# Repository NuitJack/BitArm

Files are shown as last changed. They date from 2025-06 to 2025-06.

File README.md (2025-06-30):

# BitArm
This project uses a RP Pico W shielded by the [BitDogLab](https://bitdoglab.webcontent.website/) team's PCB to recieve user inputs through a 2.4-inch SPI TFT display with 240x320 resolution, ILI9341 controller, and resistive touchscreen (XPT2046) to control the movements of a 3D printed Robotic Arm via BLE comunication with an ESP32-DevKitC-32, controlling three MG90S metal gear servos for the arm's degrees of freedom and one SG90 servo motor for the claw. This was developed during the first semester of 2025 as a collaborative project for Unicamp's practical course on embedded systems projects at [FEEC](https://www.fee.unicamp.br/). In this repository you will find everything we used to bring this project into reality. We thank both the support and instruction of the course's professor, [Dr. Fabiano Fruett](http://lattes.cnpq.br/4840178785453194), whose vision made this and many other great projects' development possible with that practical course's offering.

<p align="center">
  GIF with quick visual demo of the project
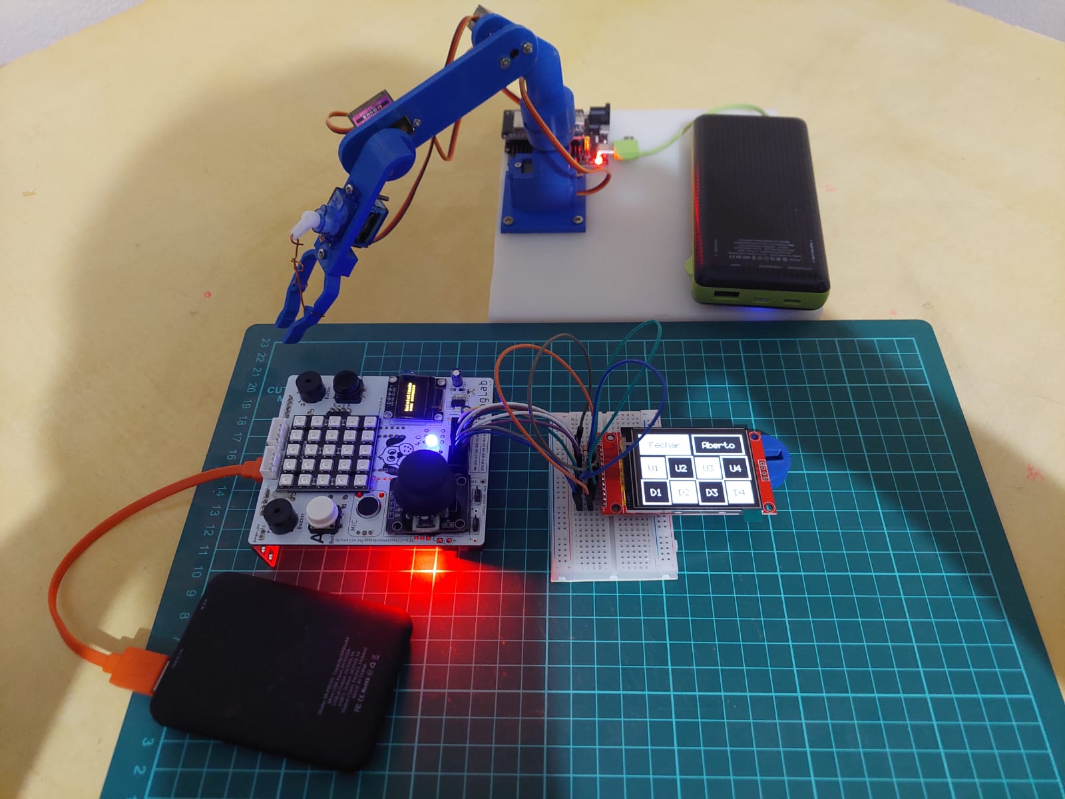
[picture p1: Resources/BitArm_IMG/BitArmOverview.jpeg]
Picture of the project
  
</p>

> Follow [this Google Drive link](https://drive.google.com/file/d/1D46ARnqftNCbvr9nV22uoLGM8FUA34ID/view?usp=sharing) to see this demo in better resolution and detail

## Directory tree
```bash
BitArm/
├── Arm/	# Contains everything that was uploaded to our ESP32 in order to control the robotic arm via BLE sent commands coded unto individual chars
├── Firmware/	# Contains the firmware file and instructions on how to build a Firmware file for RP Pico W, already with custom drivers for the display's touch and LCD interfaces
├── Resources/	# All ilustrations used for this documentation
├── main.py	# The main python routine implemented into RP Pico W, responsible for running the main user interface
└── README.md	# This file
```

## Full material list
Main set of components:
- 1x BitDogLab kit, containing a Raspberry Pi Pico W microcontroler
- 1x 2.4-inch SPI TFT display with 240x320 resolution, ILI9341 controller, and resistive touchscreen (XPT2046) with plastic pen
- 1x ESP32-DevKitC-32 with CH340C USB-Serial converter
- 1x 38-pin ESP32S NodeMCU expander. With support for USB-C and Micro USB
- 1x 20000mAh/22.5W power bank with 5V output
- 1x USB to USB-C cable
- 3x MG90S motors (base and both joints)
- 3x MG90S Horn
- 1x SG90 motor (claw)
- 1x SG90 Horn

Arm Structure:
- Structure made of PLA filament with 3D printing
- 1x 608Zz bearing

Screws and Nuts:
- MG90S Motor Mounting
  - 6x M2 X 20mm Flat Head Screws 
  - 6x Nuts for M2 Screws
- 8 sets of (1 for Claw, 6 for Joint Supports, 1 for Axis):
  - 8x M2.5 X 20mm Pan Head Screws
  - 8x Nuts for M2.4 Screws
- Base
  - 4x M4 x 10mm Screws with Superb Thread

Display wiring acessories:
- 1x Breadboard 8.5×5.5cm (400 Holes)
- 8x Male-female jumpers
- 4x Male-male jumpers
- 1x 10kΩ resistor (for pull-up)

## I have everything ready, how can I run this project?
> Please note our code is built for running with BitDogLab's shield. Consider altering the needed code in main.py if you want to run this project on your own shield. From here onwards, we'll consider the usage of BitDogLab's shield and our main.py without any changes. 

1. (Optional) Build the custom firmware with the instructions provided in the "Firmware" directory's README
2. Upload the Firmware file (provided or built locally) to the RP Pico W. You can follow [BitDogLab's tutorial](https://github.com/BitDogLab/BitDogLab/tree/main/Firmware) for this step. We strongly recomend the usage of [Thonny IDE](https://thonny.org/), given it's ease of use. [This tutorial](https://bitdoglab.webcontent.website/cursos/introducao-pratica-a-bitdoglab/aulas/usando-o-ide-thonny-para-desenvolvimento/) (in portuguese) teaches how to setup the IDE and also upload the firmware file.
3. Connect the Touch LCD display to the avaliable RP pins according to the table bellow. We also provide an image on how it looks like when using a protoboard.

<div align="center">
  
| Function | RP Pin  | Description |
|---|---|---|
| T_IRQ | GND | Touch Interrupt |
| T_DO | GP16 | Touch Data Output |
| T_DIN | GP19 | Touch Data Input |
| T_CS | GP9 | Touch Chip Select |
| T_CLK | GP18 | Touch Clock |
| SDO (MISO) | NC | Not Connected |
| LED | 3V3 | Backlight Power |
| SCK | GP18 | SPI Clock |
| SDI (MOSI) | GP19 | SPI Data Input |
| DC | GP20 | Data/Command Control  |
| RESET | 3V3 + 10kΩ | Reset with Pull-up |
| CS | GP17 | Display Chip Select |
| GND | GND | Ground |
| VCC | 3V3 | Power Supply |

</div>

4. Upload the code present in the "Arm" directory, following its README, and connect the powerbank to start anouncing the BLE.
5. Turn on both ESP and RP sides and press the "A" button for starting the BLE connection process.
6. Wait until the initialization ends. The BitDogLab's OLED display and RBG LED are visual feedbacks of the commands given, providing information on the BLE communication and the delay needed to send the next command (LED color changes)
7. Each of the buttons changes the position 'state' of the arm, coding 8 different positions, and the opening and closing of the claw.
8. Long pressing the "Fechar" button ends the execution, shutting everything down. For running again, reset the RP, remove power from the ESP and go back to step 5.

## Final considerations
Feel free to use our project as a starting point for yours! We took heavy inspiration from [iwatake](https://github.com/iwatake2222)'s [pico-mnist](https://github.com/iwatake2222/pico-mnist) project for building the drivers for the Touch LCD display and also from [Thingiverse – Robotic Arm (MG90S based)](https://www.thingiverse.com/thing:1684471) for the arm and claw designs. So don't forget to credit us if this project was useful for you in any way!

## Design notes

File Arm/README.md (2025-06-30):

# `Arm/` – ESP32 Robotic Arm Controller

This folder contains the firmware and structural files for the robotic arm used in the **BitArm project** — a BLE-controlled, 3D-printed manipulator with three degrees of freedom and a claw. The arm is actuated by **three MG90S servos** (base, shoulder, elbow) and **one SG90 servo** (claw), all controlled by an **ESP32-DevKitC-32**.

To improve stability and reduce mechanical stress on the base motor, the structure includes a **ball bearing at the rotation axis**, allowing for smoother and more reliable movement.

Commands are sent via **Bluetooth Low Energy (BLE)** from a Raspberry Pi Pico W touchscreen interface. Each command corresponds to a predefined position or claw movement, and transitions are executed smoothly to reduce mechanical stress and improve precision.

The ESP32 is mounted on a **custom shield**, which distributes power and simplifies wiring. This folder includes the control firmware (`arm_controller.c`) and mechanical design files (in the `Structure/` subfolder).

<div align="center">
  <table>
    <tr>
      <td>
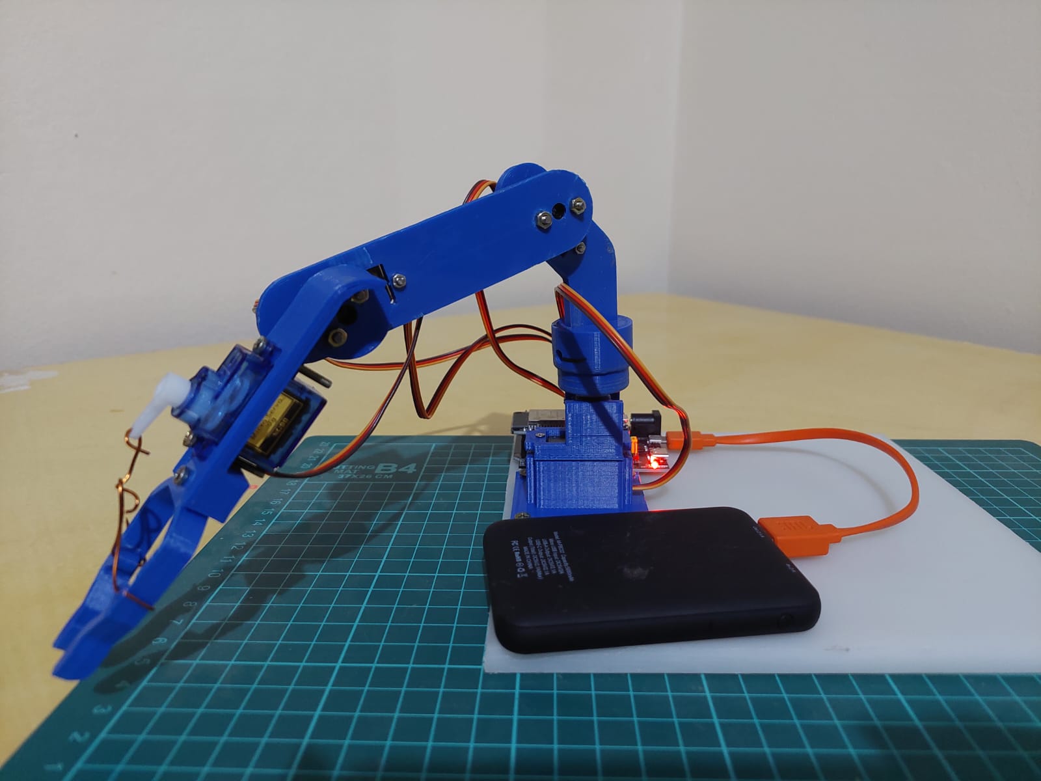
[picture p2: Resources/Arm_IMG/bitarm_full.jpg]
BitArm
        
      </td>
      <td>
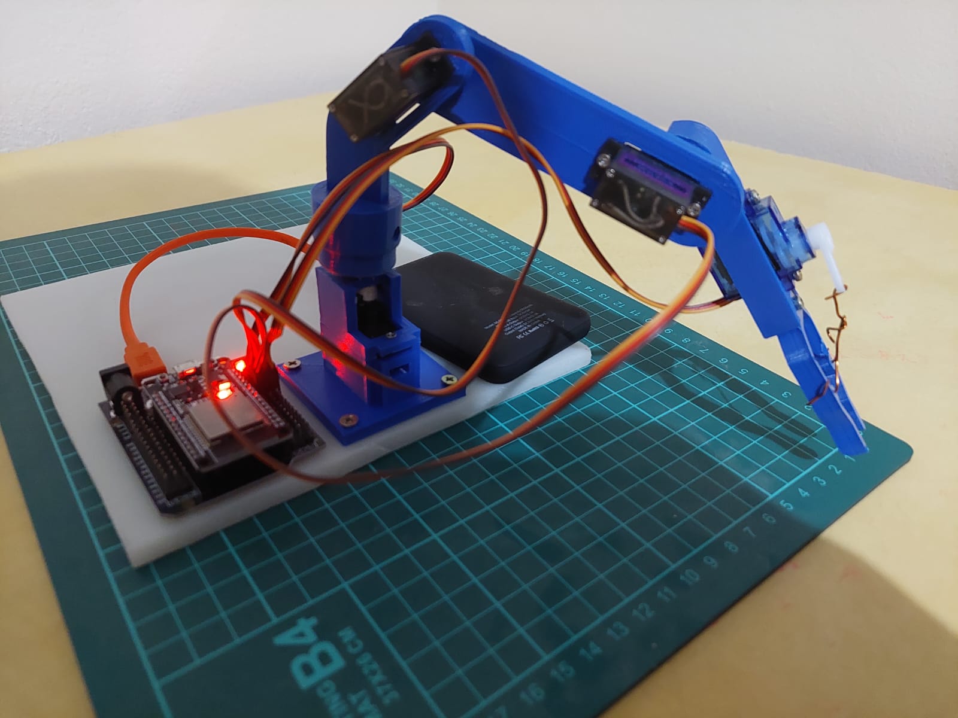
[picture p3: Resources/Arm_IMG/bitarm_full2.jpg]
BitArm Active
        
      </td>
    </tr>
  </table>
  <p><em>BitArm – Fully assembled robotic arm in idle position</em></p>
</div>

---

## Directory Tree

```bash
Arm/
├── arm_controller.c    # Firmware for ESP32 to control servos via BLE
├── Structure/          # STL files and images of the 3D-printed arm parts
├── Resources/          # Images used in documentation
└── README.md           # This file
```
---

## Bill of Materials

### Main Electronics

| Component | Quantity | Description | Image |
|---|---|---|---|
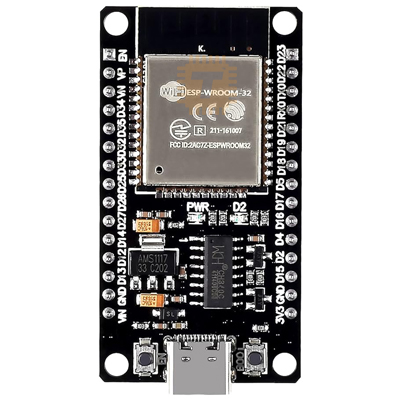
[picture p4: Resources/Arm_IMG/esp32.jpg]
ESP32
| ESP32-DevKitC-32 | 1x | With CH340C USB-Serial converter |  |
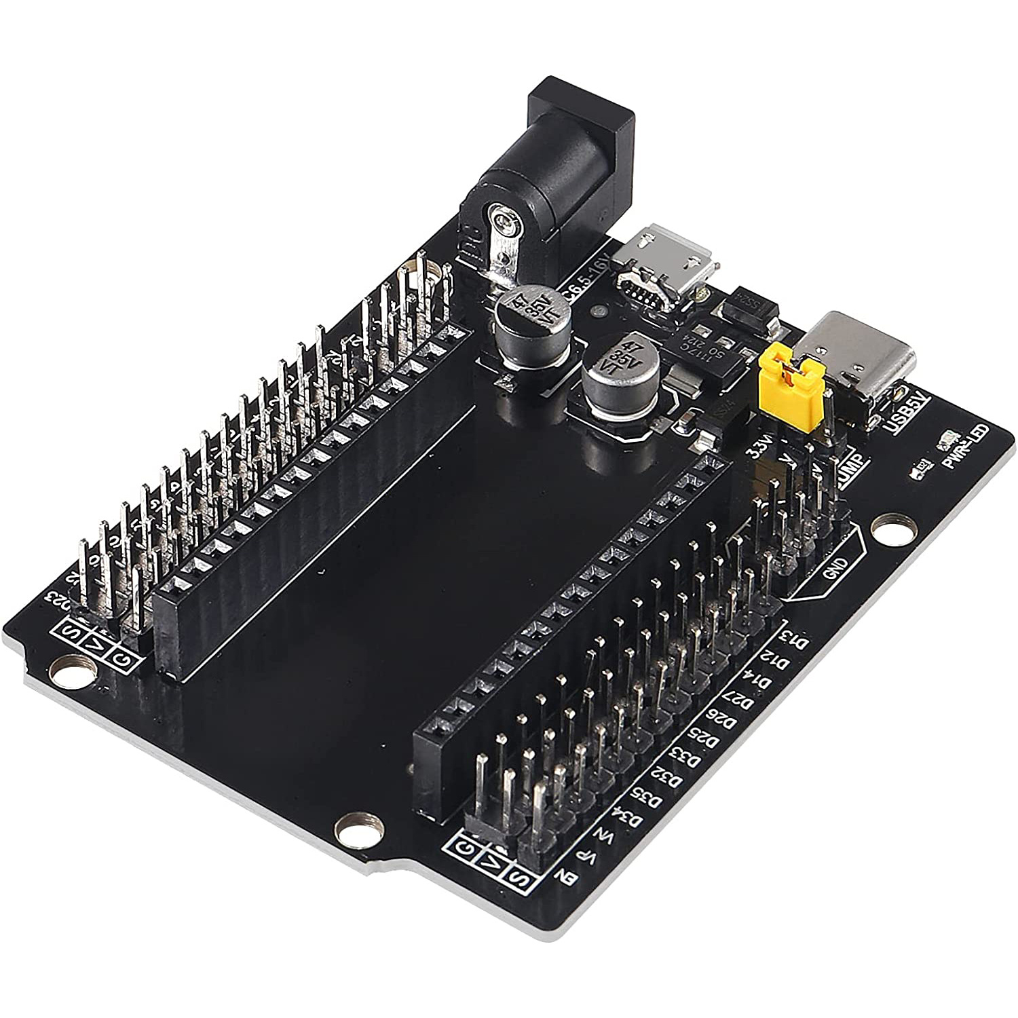
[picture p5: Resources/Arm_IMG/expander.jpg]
EXPANDER
| ESP32S NodeMCU Shield | 1x | 30 pin ESP32 interface with power distribution |  |
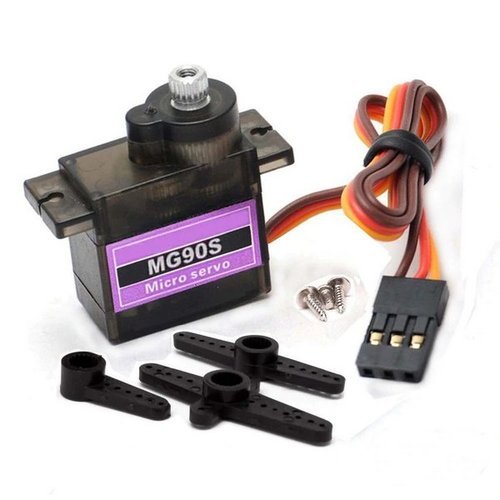
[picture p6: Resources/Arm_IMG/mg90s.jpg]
MG90S
| MG90S Servo Motor | 3x | Metal gear servos (base, shoulder, elbow)  |  |
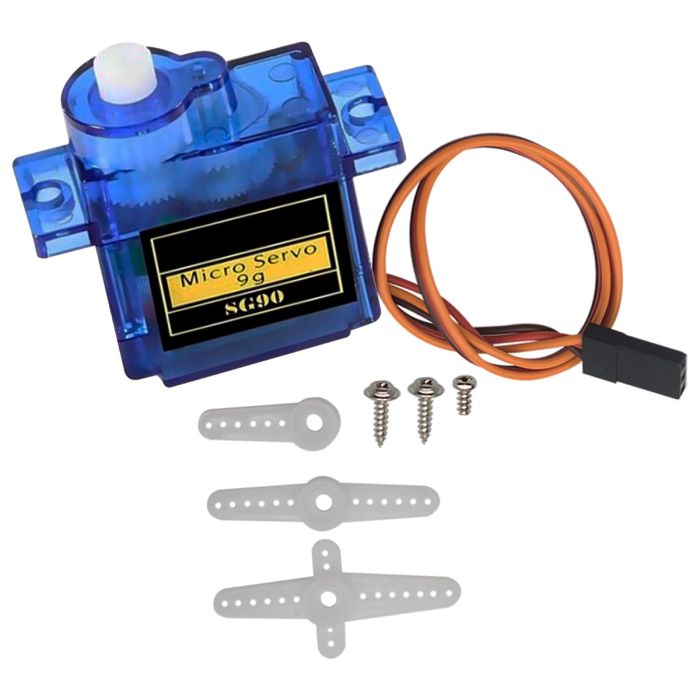
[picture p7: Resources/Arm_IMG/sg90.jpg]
SG90
| SG90 Servo Motor | 1x | Claw actuation |  |
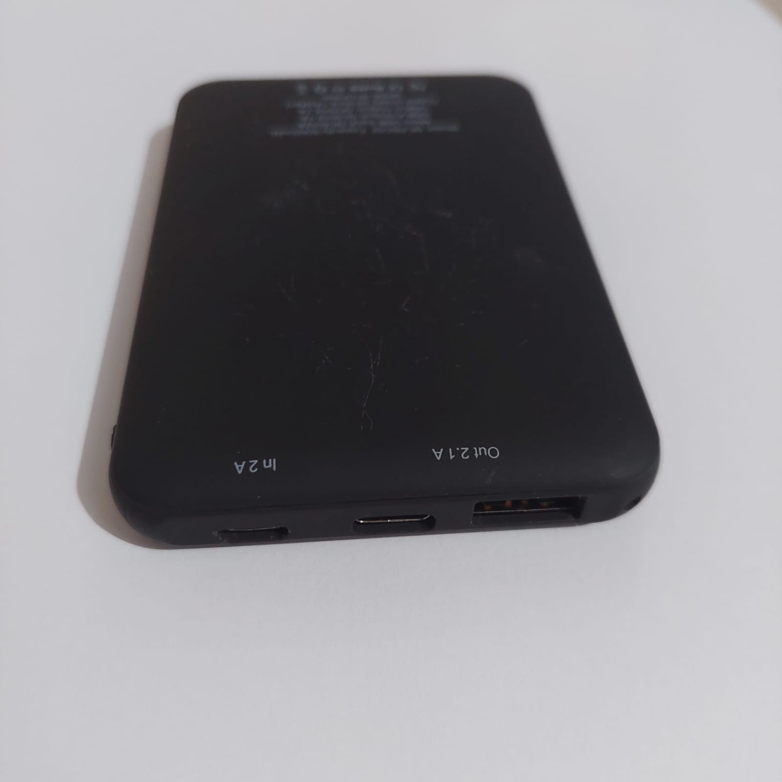
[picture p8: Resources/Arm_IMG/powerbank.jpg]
POWERBANK
| Power Bank | 1x | 20000mAh / 22.5W, 5V output |  |
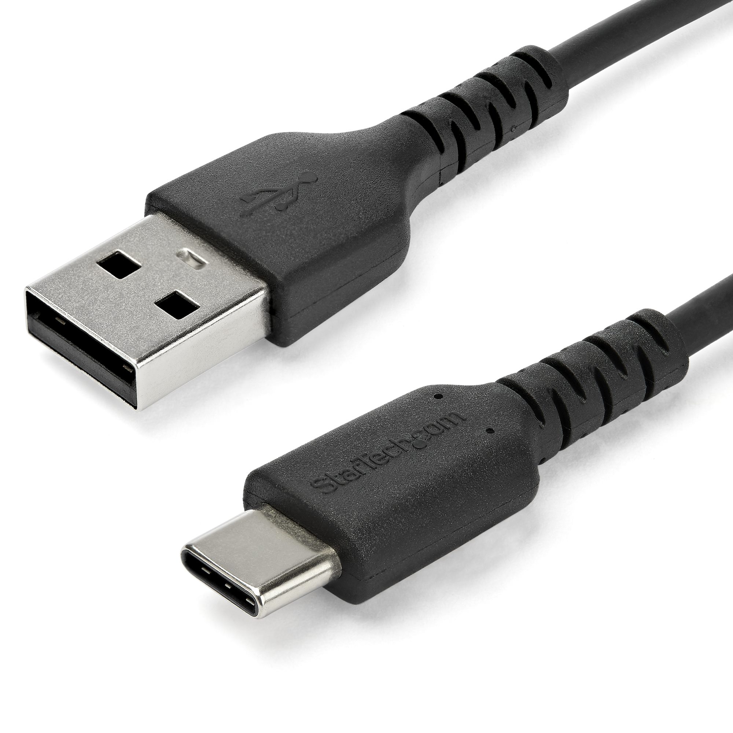
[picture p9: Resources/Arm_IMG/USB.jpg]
USB
| USB-A to USB-C Cable | 1x | USB-A to USB-C for power |  |

---

### Arm Structure

| Component | Quantity | Description | Image |
|---|---|---|---|
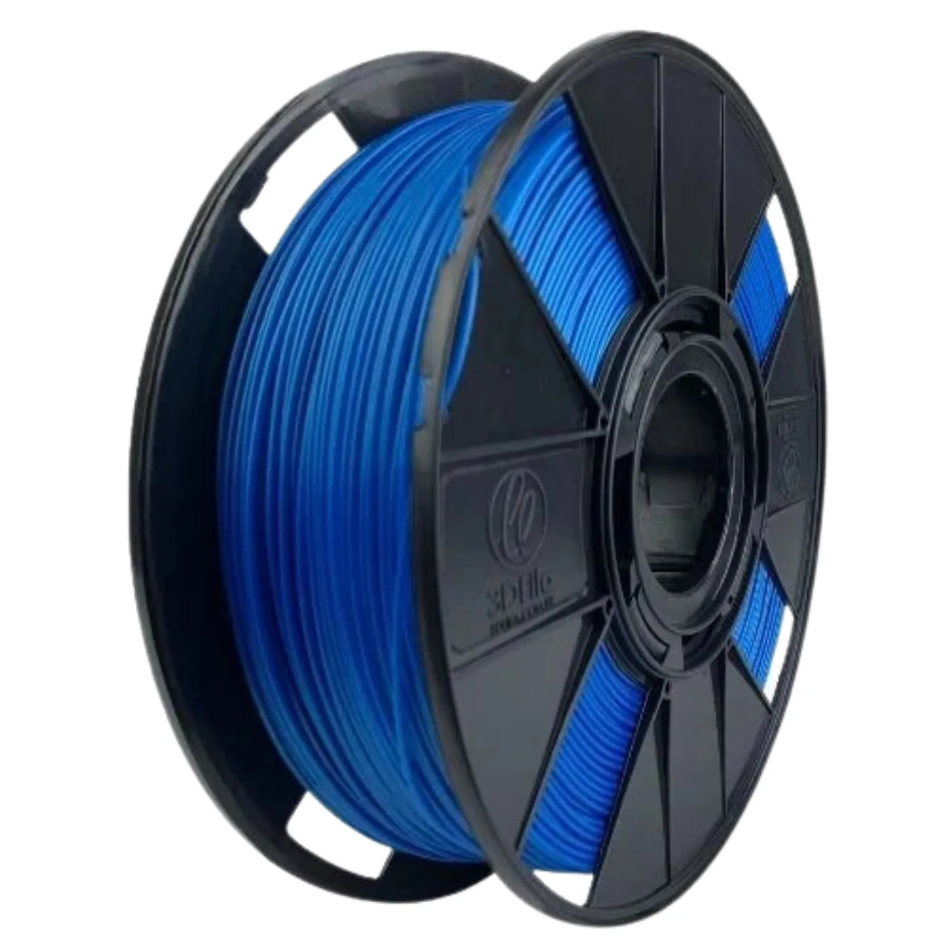
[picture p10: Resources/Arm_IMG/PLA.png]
PLA
| Printed Frame | 1x | 3D-printed in PLA |  |
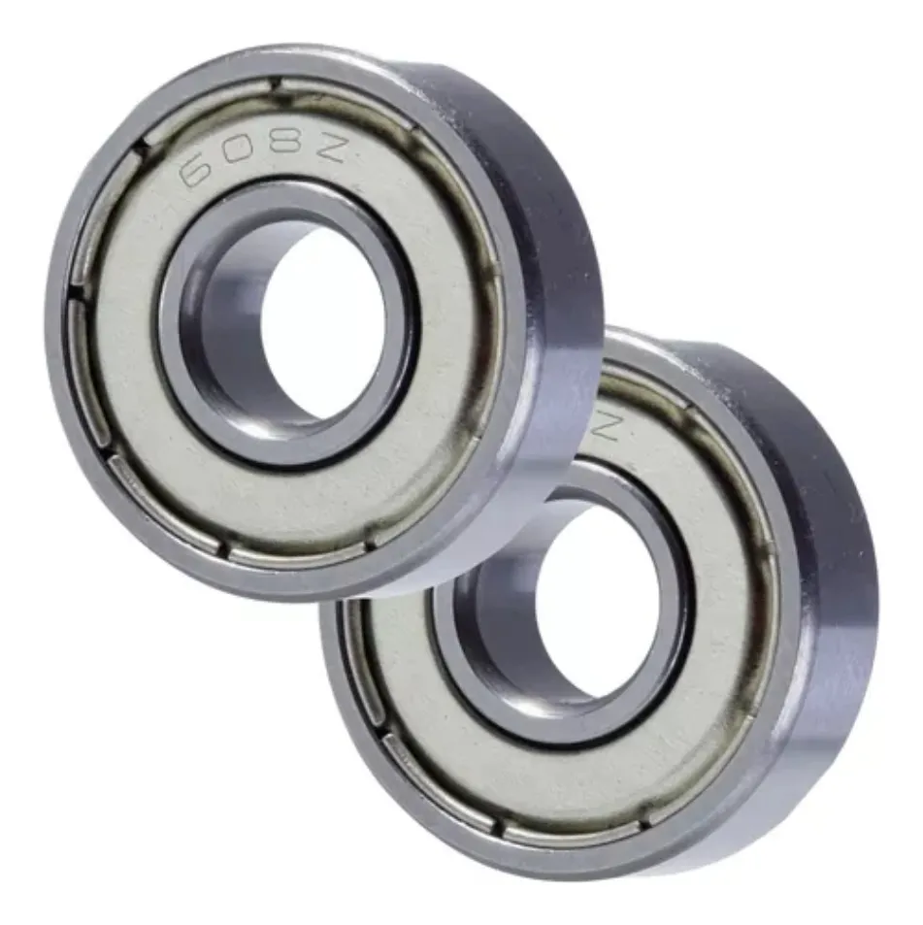
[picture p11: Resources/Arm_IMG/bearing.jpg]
BEARING
| 608Zz Bearing | 1x | For base axis smooth rotation |  |

---

### Screws and Fasteners

| Purpose | Quantity | Specification |
|---|---|---|
| MG90S Mounting | 6x | M2 x 20mm flat head screws + M2 nuts |
| Joint Supports + Claw | 8x | M2.5 x 20mm pan head screws + M2.4 nuts |
| Base Fixation | 4x | M4 x 10mm self-threading screws |

---

## Power Supply

- The robotic arm requires a **5V power source** capable of delivering at least **2.5A** to operate safely and reliably.
- A **20000mAh / 22.5W USB power bank** is recommended for portability and stable current delivery. But an equivalent Lithium battery also can be used.
- **Do not power the ESP32 and servos via a computer USB port**, as it cannot supply sufficient current for all motors.
- The **custom ESP32 shield** ensures clean power distribution to all components, preventing voltage drops and unexpected resets during motion.

---

## 📡 Pin Mapping (ESP32 → Servos)

| Function | GPIO (ESP32) | Description |
|---|---|---|
| Base Servo | 13 | Rotates the base (horizontal axis) |
| Shoulder | 12 | Lifts the upper arm (vertical axis)|
| Elbow | 14 | Moves the forearm (vertical axis)  |
| Claw Servo | 27 | Opens and closes the claw |

- **PWM Frequency:** 50 Hz  
- **PWM Resolution:** 16 bits  
- **Duty Cycle Mapping:** `1638` (0°) → `8192` (180°)

---

## BLE Command Protocol

The robotic arm receives commands via **Bluetooth Low Energy (BLE)** — a low-power wireless communication protocol commonly used in embedded and IoT devices.

Each command is sent as a single character and interpreted by the ESP32 as follows:

| Command | Action |
|---|---|
| `'0'`–`'7'` | Move to one of eight preset positions |
| `'8'` | Open the claw (to 60°) |
| `'9'` | Close the claw (to 120°) |

Servo transitions are performed smoothly to reduce mechanical stress and improve motion precision.

---

## How to Use

1. Open the `Arm/` folder in **PlatformIO**, using the **ESP32 DevKitC** environment.
2. Upload `arm_controller.c` to your ESP32 board.
3. Connect the ESP32 to a **5V power source** (e.g., power bank) via the custom shield.
4. On the Raspberry Pi Pico W, start the BLE interface and press the **“A” button** on the touchscreen.
5. Once connected, use the touch interface to send commands (`'0'`–`'9'`) to the arm.
6. The ESP32 receives the BLE command and moves the servos smoothly to the target position or claw state.

---

## Final Considerations

This robotic arm structure was inspired by the open-source design shared at [Thingiverse – Robotic Arm (MG90S based)](https://www.thingiverse.com/thing:1684471). While the **claw mechanism** was directly adapted from that model — with minor adjustments for fit and integration — the rest of the structure was designed in  Tinkercad, using the former [Thingiverse](https://www.thingiverse.com/thing:1684471) project as a reference to design pieces that suit the specific goals and constraints of this project.

One of the key structural improvements made in this design was the addition of a **608Zz ball bearing at the base**. This enhancement significantly reduces the mechanical load on the base servo motor, providing:

- **Smoother rotational motion**
- **Greater stability**
- **Reduced wear on the servo gear system**

The result is a more robust and precise base movement, especially useful in setups where the arm must rotate frequently or support added mass.

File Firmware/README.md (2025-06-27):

# Firmware compilation for RP Pico W integration with Touch LCD
If you just want to run this project without recompiling it's firmware, just download "firmware.uf2" and use it as instructed in the main README. The following text explains how it was compiled and how can you do it yourself.

## How to use this folder to compile RP's firmware
1. Clone this repository locally with `git clone https://github.com/NuitJack/BitArm.git`.
2. Download [this toolchain](https://developer.arm.com/-/media/Files/downloads/gnu/12.3.rel1/binrel/arm-gnu-toolchain-12.3.rel1-x86_64-arm-none-eabi.tar.xz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) from [ARM](https://developer.arm.com/downloads/-/arm-gnu-toolchain-downloads), and unzip it inside the "`tools`" folder (see expected tree in the README file inside that folder).
3. Open a terminal inside this folder (`Firmware`).
4. Make sure that both "`build.sh`" and "`setup_submodules.sh`" have excecution permission (you can also run their command lines by hand, your choice).
5. Make sure that "CMake" and "make" are working properly on your computer.
6. Execute "`build.sh`". The first time will take longer, since it will update all of micropython's submodules before building.
7. The built firmware will be inside the generated "`build/output` folder.

This folder is building micropython v1.22.2 (editable within "`setup_submodules.sh`") with 4 modules from [BitDogLab](https://github.com/BitDogLab/BitDogLab/tree/main/libs)'s repository (`ahtx0.py`, `bh1750.py`, `matriz_bdl.py` and `ssd1306.py`) and 2 custom modules made to supply the needed comunication between the RP core and the Touch LCD display used (`ili9341.py` and `tsc2046.py`).

## How can I add my own python modules in the firmware?
1. Add the file with your module inside "`externals/libs`" (the file's name will be the name of the module)
2. Add the line `freeze("external/libs", "yourfilename.py")` at the end of "`manifest.py`"
3. Run "`build.sh`" and change the firmware file for the newly built one
4. Check if your module is avaliable with `help('modules')`
5. Add it to your "`main.py`" as usual (`include yourfilename`)

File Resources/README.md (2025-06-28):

# All ilustrations used for this documentation

```bash
Resources/
├── BitArm_IMG/          # Main repository resources
├── Arm_IMG/             # Arm sub-repository resources
└── README.md            # This file
```

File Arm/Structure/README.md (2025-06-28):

# `Structure/` – 3D-Printed Components for the Robotic Arm

This folder contains all STL files and documentation for the 3D-printed mechanical structure of the BitArm robotic arm. The entire model was designed in **Tinkercad**, with a focus on modularity, ease of assembly, and compatibility with MG90S and SG90 servo motors.

The design consists of **seven core components**: base motor mount, bearing support, rotating base, shoulder bracket, forearm, elbow, and claw; enabling **3 degrees of freedom** and **gripper functionality**. The parts were made to be fitted for standard metric fasteners M2 and M2.5.

---

## Assembled Overview

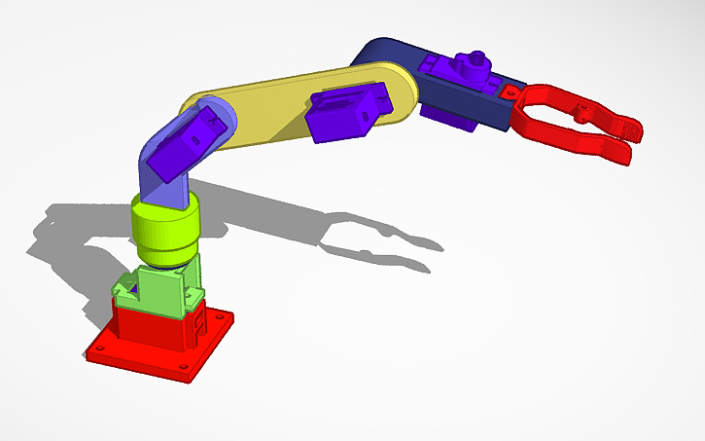
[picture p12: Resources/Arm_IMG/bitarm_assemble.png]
Full Arm Assembled


*Fully assembled BitArm exemple, with all printed modules connected*

---

## Components Overview

Each printed piece is described below with its purpose, assembly considerations, and STL filename.

---

### 1. Base Motor Cover  
**STL:** `Base Motor Cover.stl`

- Houses the **MG90S servo** responsible for horizontal base rotation.
- Includes holes for **M2 screws and nuts** to fasten the motor.
- Has a cable passthrough for neat wiring.
- Mounting holes at the bottom allow it to be fixed to a heavier base using **M2.5 screws**.

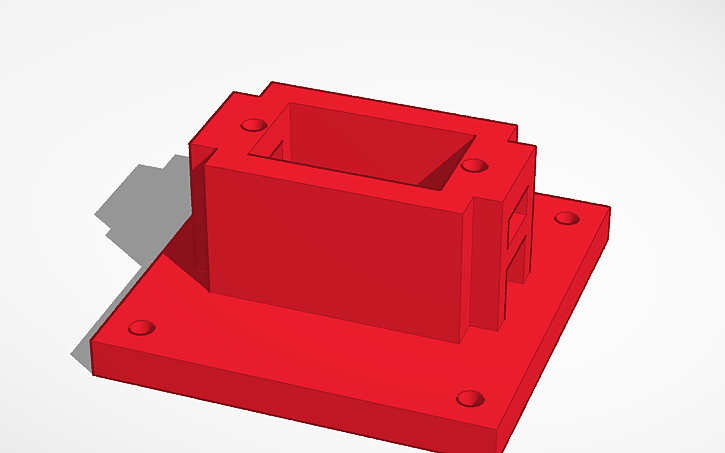
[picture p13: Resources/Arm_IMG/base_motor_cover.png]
Base Motor Cover


---

### 2. Ball Bearing Support  
**STL:** `Ball Bearing Support.stl`

- Goes between the motor and the bearing (608Zz).
- Ensures the **bearing is centered on the motor shaft**.
- Prevents external contact between the bearing and static structure.

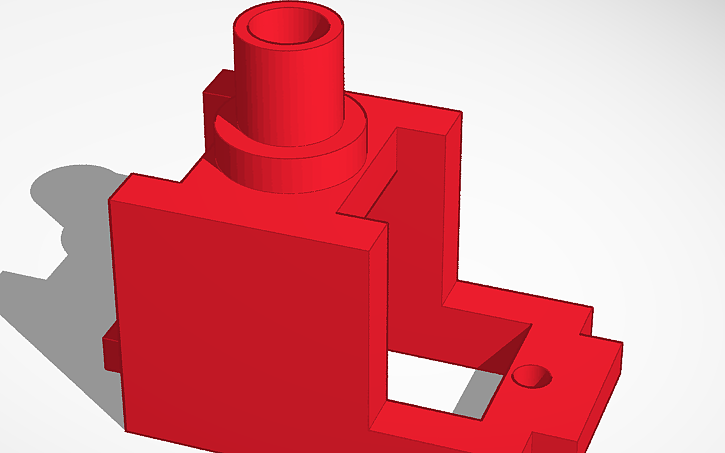
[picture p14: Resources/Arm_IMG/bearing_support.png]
Bearing Support


---

### 3. Rotatory Base  
**STL:** `Rotatory Base.stl`

- Sits on top of the 608Zz bearing and rotates with the motor horn.
- Supports the shoulder structure (and by extent the whole arm).
- Includes a **rectangular cutout** to insert the next joint (shoulder).

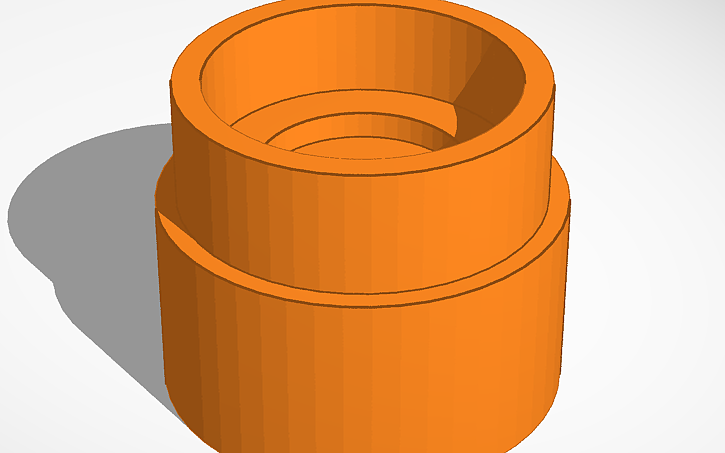
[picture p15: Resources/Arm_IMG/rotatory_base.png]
Rotatory Base


---

### 4. Shoulder  
**STL:** `Shoulder.stl`

- Mounts the **second MG90S servo** (Upper Arm movement).
- Fixes onto the rotatory base and acts as the **first articulation joint**.

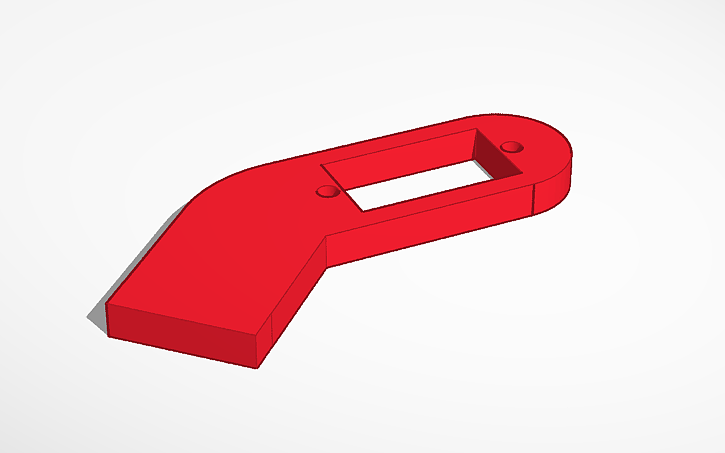
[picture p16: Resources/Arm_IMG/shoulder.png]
Shoulder


---

### 5. Upper Arm  
**STL:** `Upper Arm.stl`

- Connected to the shoulder via servo horn.
- Includes mount for the **third MG90S servo**, which actuates the elbow, articulating the Forearm.

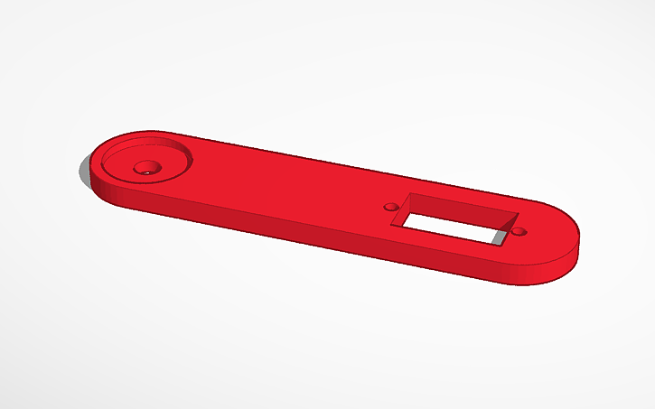
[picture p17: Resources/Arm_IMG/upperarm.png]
Forearm


---

### 6. Forearm  
**STL:** `Forearm.stl`

- Mounts onto the elbow servo, linked to the Upper Arm.
- Holds the **SG90 servo** used to open and close the claw.
- Features a back slot to insert and fasten the claw.

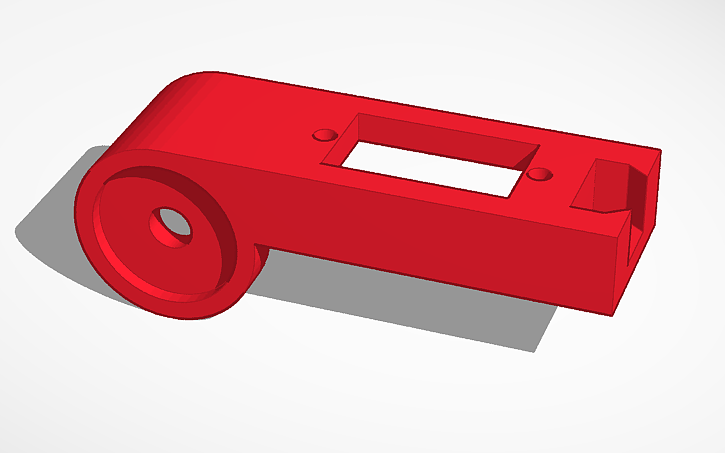
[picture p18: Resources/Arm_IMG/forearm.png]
Elbow Arm


---

### 7. Claw  
**STL:** `Claw.stl`

- This part is a **direct adaptation** of the [gripper design available on Thingiverse](https://www.thingiverse.com/thing:1684471), modified slightly to fit this arm’s mechanical structure.
- Connected to the **SG90 servo**, it operates using a wire or string pulled by the servo horn to open and close.
- Includes two rear holes for mounting — can be clipped into the elbow or fixed with screws if needed.

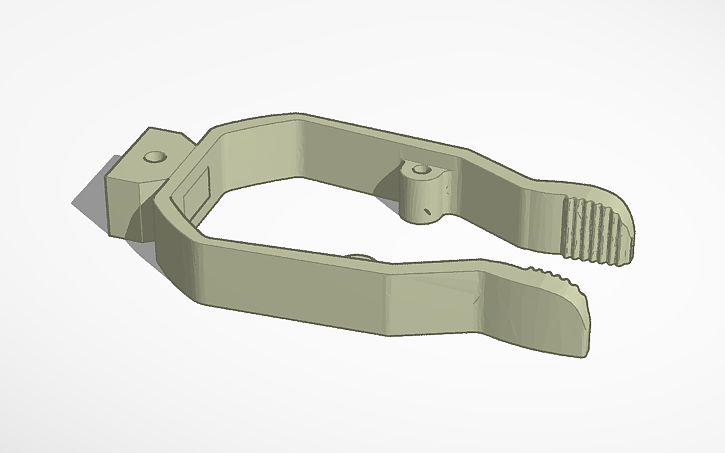
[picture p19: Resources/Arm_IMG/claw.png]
Claw


## Printing and Assembly Notes

- All parts **above** were printed in **PLA**, with tolerances carefully adjusted for **tight press fits**.
- No glue is required — all parts **above** are either **screw-mounted** or **slot-fitted**.
- The **rotational axis** of the arm is currently implemented using **two metal screws linked together**:
  - One screw attaches directly to the **motor horn**, providing rotational drive.
  - The second screw passes **transversely through the Rotatory Base**, securing it to the Ball Bearing Support and enabling a stable, centered rotation.
- In future revisions, a **fully 3D-printable axle** will be included in this repository to simplify assembly and reduce dependency on external hardware.

**Recommended print settings:**
- Layer height: `0.2mm`
- Infill: `≥20%`

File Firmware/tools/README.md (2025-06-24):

This is where you should unpack the arm toolchain. Running `tree -L 3` here should result in:
```.
└── arm-gnu-toolchain-12.3.rel1-x86_64-arm-none-eabi
    ├── 12.3.rel1-x86_64-arm-none-eabi-manifest.txt
    ├── arm-none-eabi
    │   ├── bin
    │   ├── include
    │   └── lib
    ├── bin
    │   ├── arm-none-eabi-addr2line
    │   ├── arm-none-eabi-ar
    │   ├── arm-none-eabi-as
    │   ├── arm-none-eabi-c++
    │   ├── arm-none-eabi-c++filt
    │   ├── arm-none-eabi-cpp
    │   ├── arm-none-eabi-elfedit
    │   ├── arm-none-eabi-g++
    │   ├── arm-none-eabi-gcc
    │   ├── arm-none-eabi-gcc-12.3.1
    │   ├── arm-none-eabi-gcc-ar
    │   ├── arm-none-eabi-gcc-nm
    │   ├── arm-none-eabi-gcc-ranlib
    │   ├── arm-none-eabi-gcov
    │   ├── arm-none-eabi-gcov-dump
    │   ├── arm-none-eabi-gcov-tool
    │   ├── arm-none-eabi-gdb
    │   ├── arm-none-eabi-gdb-add-index
    │   ├── arm-none-eabi-gfortran
    │   ├── arm-none-eabi-gprof
    │   ├── arm-none-eabi-ld
    │   ├── arm-none-eabi-ld.bfd
    │   ├── arm-none-eabi-lto-dump
    │   ├── arm-none-eabi-nm
    │   ├── arm-none-eabi-objcopy
    │   ├── arm-none-eabi-objdump
    │   ├── arm-none-eabi-ranlib
    │   ├── arm-none-eabi-readelf
    │   ├── arm-none-eabi-size
    │   ├── arm-none-eabi-strings
    │   └── arm-none-eabi-strip
    ├── include
    │   └── gdb
    ├── lib
    │   ├── bfd-plugins
    │   └── gcc
    ├── libexec
    │   └── gcc
    ├── license.txt
    └── share
        ├── doc
        ├── gcc-12.3.1
        ├── gcc-arm-none-eabi
        ├── gdb
        ├── info
        └── man

21 directories, 33 files
```

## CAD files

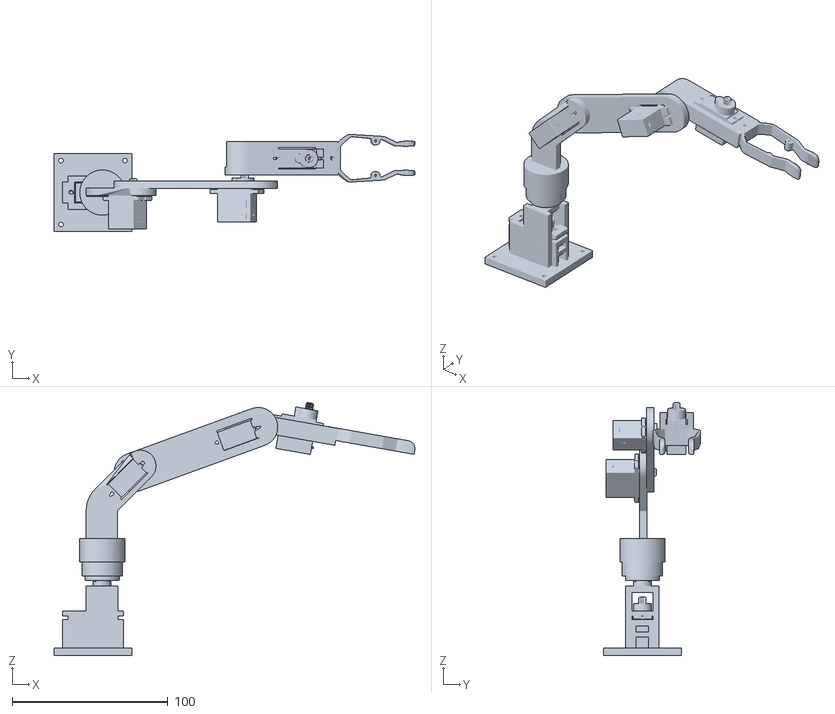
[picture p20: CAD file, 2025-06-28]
Arm/Structure/Assembled 3D Structure.stl
231.5 x 62.3 x 162.3

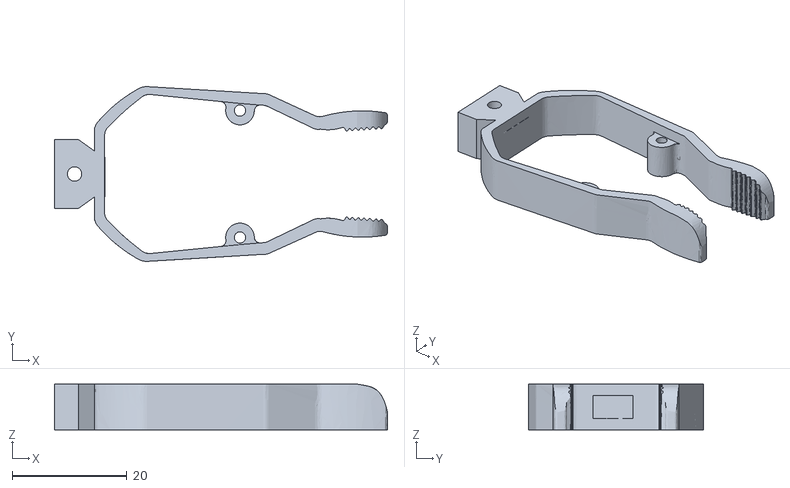
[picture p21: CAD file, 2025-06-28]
Arm/Structure/Claw.stl
58.1 x 30.5 x 8.00

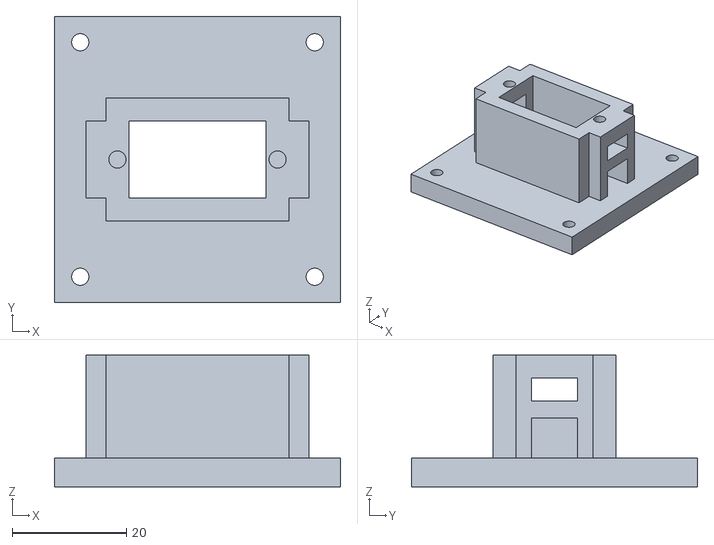
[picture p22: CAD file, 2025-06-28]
Arm/Structure/Base Motor Cover.stl
50.0 x 50.0 x 23.0

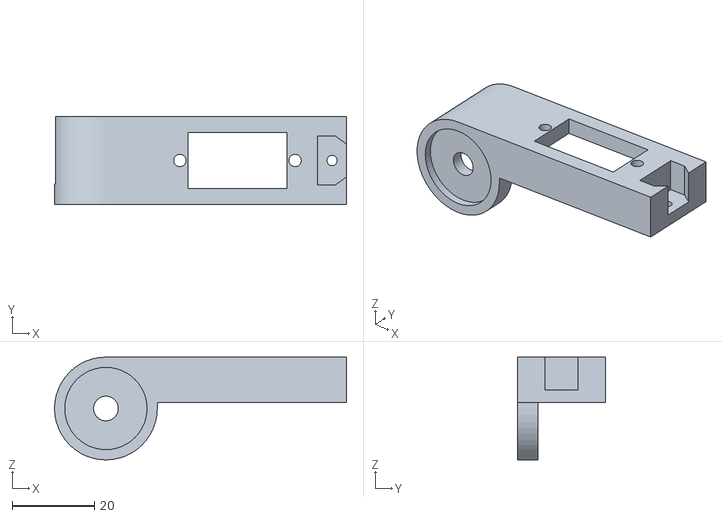
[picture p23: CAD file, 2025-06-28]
Arm/Structure/Forearm.stl
71.0 x 21.5 x 25.0

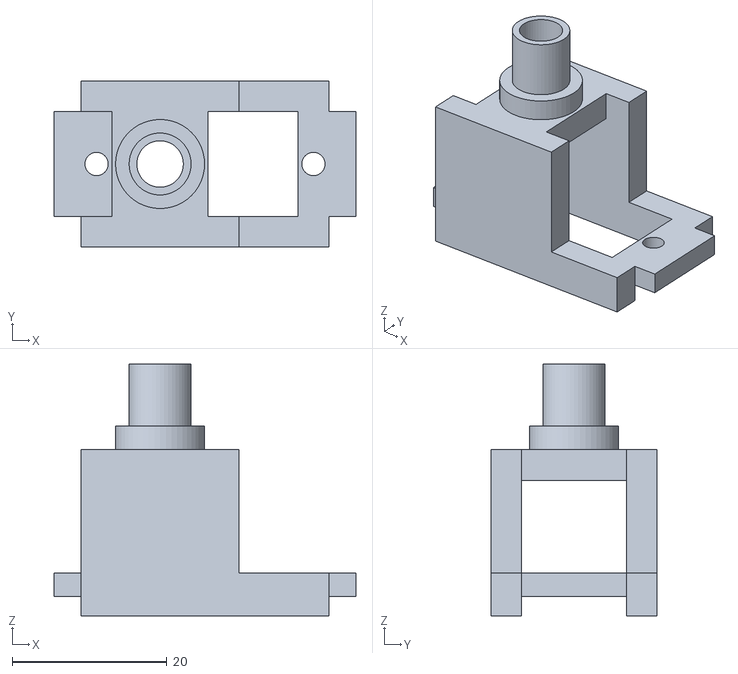
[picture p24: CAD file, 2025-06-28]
Arm/Structure/Ball Bearing Support.stl
39.0 x 21.5 x 32.5

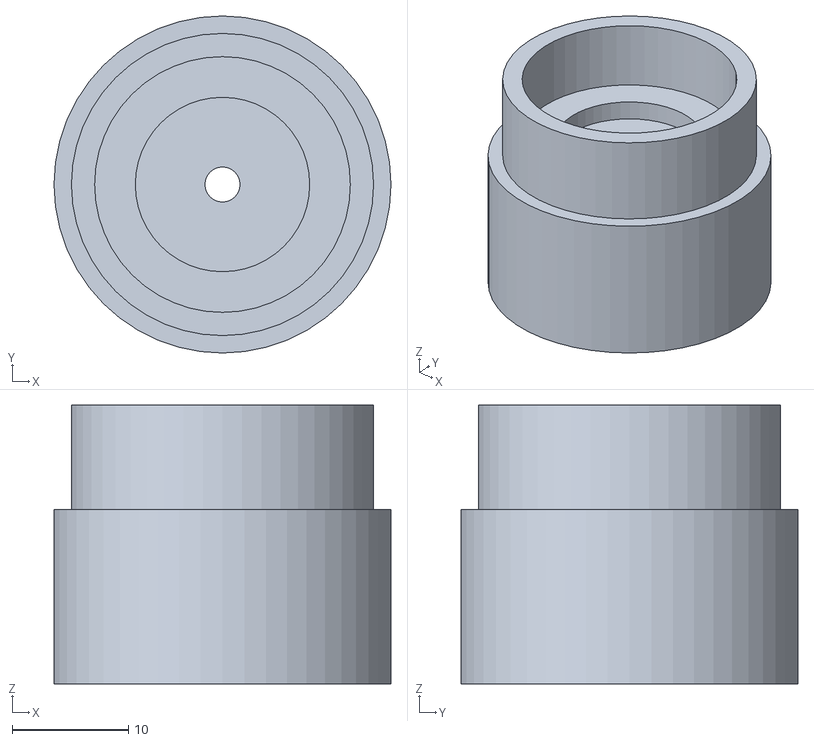
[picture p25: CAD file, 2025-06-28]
Arm/Structure/Rotatory Base.stl
29.0 x 29.0 x 24.0

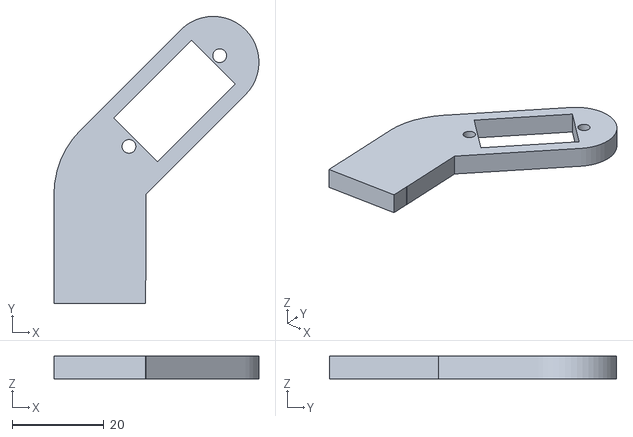
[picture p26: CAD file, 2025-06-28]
Arm/Structure/Shoulder.stl
44.7 x 62.7 x 5.00

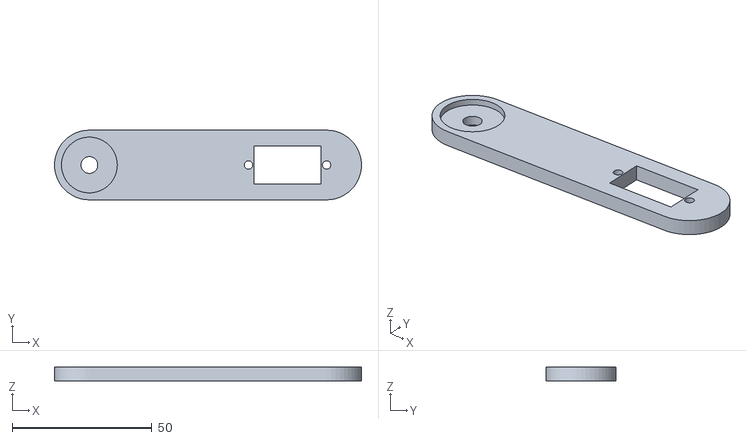
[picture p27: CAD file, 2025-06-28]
Arm/Structure/Arm.stl
110.0 x 25.0 x 5.00

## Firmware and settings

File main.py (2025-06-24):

import aioble
import bluetooth
import struct
import uasyncio as asyncio
import machine
import utime
from ili9341 import ILI9341
from tsc2046 import TSC2046
from ssd1306 import SSD1306_I2C

class BLE_Sender:
    
    # Inicializa os parâmetros de conexão necessários para a comunicação com a ESP32
    def __init__(self, device_name="PicoBLE"):
        self._SERVICE_UUID = bluetooth.UUID("12345678-1234-5678-1234-56789abcdef0")
        self._CHAR_UUID = bluetooth.UUID("abcdef01-2345-6789-abcd-0123456789ab")
        self.device_name = device_name
        self.conectado = False
        self.characteristic = None
        self.connection = None

    # Rotina de conexão com a ESP32
    async def conectar(self):
        print("Procurando ESP32...")
        device = None
        try:
            # Scan por 5 segundos (5000ms), com janela de 3 segundos (3000ms)
            async with aioble.scan(5000, 3000) as scanner:
                async for result in scanner:
                    print("Dispositivo encontrado:", result.name())
                    if result.name() == "ESP32_BRAÇO_BLE":
                        print("ESP32 encontrada!")
                        device = result.device
                        break
            if not device:
                print("ESP32 não encontrada.")
                return False
            print("Conectando...")
            try:
                # Tentar conectar com timeout de 10 segundos
                self.connection = await asyncio.wait_for(device.connect(), 10)
                print("Conectado, buscando serviços...")
                service = await self.connection.service(self._SERVICE_UUID)
                self.characteristic = await service.characteristic(self._CHAR_UUID)
                utime.sleep_ms(3000)
                self.conectado = True
                print("Conectado com sucesso!")
                return True
                
            except asyncio.TimeoutError:
                print("Timeout na conexão")
                return False
            except Exception as e:
                print("Erro durante conexão:", e)
                return False
                
        except Exception as e:
            print("Erro durante scan:", e)
            return False

    # Rotina de desconexão com a ESP32
    async def desconectar(self):
        if self.connection:
            try:
                await self.connection.disconnect()
            except:
                pass
        self.connection = None
        self.characteristic = None
        self.conectado = False
        print("Desconectado.")

    # Rotina de envio de caracteres para a ESP32. Todos os comandos comunicáveis estão codificados nos caracteres numéricos de 0 a 9. Essa rotina também exibe no OLED o comando enviado
    async def enviar_caractere(self, caractere, oled, s, x, oled_print=True):
        if not self.conectado or self.characteristic is None:
            print(f"Erro: Não conectado a dispositivo BLE ou dispositivo não disponível {self.conectado} {self.characteristic}")
            return False
        try:
            dados = str(caractere).encode('utf-8')
            
            await self.characteristic.write(dados, True)
            if oled_print:
                oled_write("Comando enviado:", 0, 20, oled, fill=True)
                oled_write(s, x, 30, oled)
            print(f"Caractere '{caractere}' enviado")
            return True
        except Exception as e:
            if e is not None:
                print(f"Erro ao enviar caractere '{caractere}':", e)
                return False

# Rotina necessária uma vez que o barramento SPI é compartilhado tanto para o touch (mais lento) quanto para o LCD (mais rápido)
def set_spi_speed(speed, spi):
    spi.init(baudrate=speed)

# Rotina que implementa a animação de exibição dos dois botões superiores (estado: fechar/aberto)
def abrir(cor1, cor2, display):
    display.fill_rect(5, 165, 150, 70, cor1)
    display.fill_rect(165, 165, 150, 70, cor1)
    display.fill_rect(170, 170, 140, 60, cor2)
    display.text('Fechar', 35, 185, fg_color=cor2, bg_color=cor1, scale=3)
    display.text('Aberto', 193, 185, fg_color=cor1, bg_color=cor2, scale=3)

# Rotina que implementa a animação de exibição dos dois botões superiores (estado: fechado/abrir)
def fechar(cor1, cor2, display):
    display.fill_rect(5, 165, 150, 70, cor1)
    display.fill_rect(165, 165, 150, 70, cor1)
    display.fill_rect(10, 170, 140, 60, cor2)
    display.text('Fechado', 25, 185, fg_color=cor1, bg_color=cor2, scale=3)
    display.text('Abrir', 200, 185, fg_color=cor2, bg_color=cor1, scale=3)

# Rotina que implementa a animação de exibição dos oito botões inferiores
def montar_botoes(cor1, cor2, display, fill=True):
    if fill : display.fill(cor2)
    largura_quadrado = 320 // 4
    altura_quadrado = 240 // 3
    s = "D"
    for linha in range(2):
        k = '1'
        for coluna in range(4):
            s += k
            k = str(int(k) + 1)
            x = coluna * largura_quadrado
            y = linha * altura_quadrado
            if (linha + coluna) % 2 == 0:
                cor = cor1
                comp = cor2
            else:
                cor = cor2
                comp = cor1
            display.fill_rect(x, y, largura_quadrado, altura_quadrado, cor)
            display.fill_rect(x+5, y+5, largura_quadrado-10, altura_quadrado-10, comp)
            display.text(s, x + largura_quadrado//2 - 15, y + altura_quadrado//2 - 15, fg_color=cor, bg_color=comp, scale=3)
            s = s[:-1]
        s = "U"

# Rotina que muda a cor do led da BitDogLab
def led(r, g, b, led_r, led_g, led_b):
    led_r.duty_u16(int(r * 65535 / 255))
    led_g.duty_u16(int(g * 65535 / 255))
    led_b.duty_u16(int(b * 65535 / 255))
    
# Rotina que toca uma música (escrita em duty cycles) nos auto falantes da BitDogLab
def play(musica, alto_falante):
    for nota, duracao in musica:
        freq = nota
        alto_falante.freq(freq if freq > 0 else 500)
        alto_falante.duty_u16(32767 if freq > 0 else 0)
        utime.sleep_ms(120 * duracao)
        alto_falante.duty_u16(0)
        utime.sleep_ms(50)

# Rotina que escreve um texto s a partir da coordenada x y no display OLED da BitDogLab
def oled_write(s, x, y, oled, fill=False):
    if fill : oled.fill(0)
    oled.text(s, x, y)
    oled.show()

# Rotina que inicializa todos os periféicos da BitDogLab que são utilizados no projeto
def init_bitdog():
    led_r = machine.PWM(machine.Pin(12))
    led_g = machine.PWM(machine.Pin(11))
    led_b = machine.PWM(machine.Pin(13))
    alto_falante = machine.PWM(machine.Pin(4))
    led_r.freq(1000)
    led_g.freq(1000)
    led_b.freq(1000)
    i2c_oled = machine.SoftI2C(scl=machine.Pin(15), sda=machine.Pin(14))
    oled = SSD1306_I2C(128, 64, i2c_oled)
    oled.fill(0)
    oled.show()
    return led_r, led_g, led_b, alto_falante, oled

# Rotina de inicialização da comunicação SPI, do LCD e do touch, além das devidas calibrações e uma primeira exibição dos botões.
def init(cor1, cor2):
    spi = machine.SPI(0,
                      baudrate=30_000_000,
                      sck=machine.Pin(18),
                      mosi=machine.Pin(19),
                      miso=machine.Pin(16))
    display = ILI9341(spi, 
                      dc=machine.Pin(20),
                      cs=machine.Pin(17),
                      WIDTH=320,
                      HEIGHT=240,
                      rst=None)
    montar_botoes(cor1, cor2, display)
    abrir(cor1, cor2, display)
    set_spi_speed(1_000_000, spi)
    touch = TSC2046(spi,
                    cs=machine.Pin(9),
                    irq=None)
    CALIB_X_MIN = 1880
    CALIB_X_MAX = 150
    CALIB_Y_MIN = 270
    CALIB_Y_MAX = 1830
    touch.set_calibration((CALIB_X_MIN, CALIB_X_MAX, CALIB_Y_MIN, CALIB_Y_MAX))
    return display, touch, spi

# Animação responsável pela responsividade dos dois botões superiores
def tocar_garra(x, cor1, cor2, display, s):
    display.fill_rect(x+5, 165, 150, 70, cor1)
    if s == 'Fechar':
        display.text('Fechar', 35, 185, fg_color=cor2, bg_color=cor1, scale=3)
    elif s == 'Fechado':
        display.fill_rect(x+10, 170, 140, 60, cor2)
        display.text('Fechado', 25, 185, fg_color=cor1, bg_color=cor2, scale=3)
    elif s == 'Abrir':
        display.text('Abrir', 200, 185, fg_color=cor2, bg_color=cor1, scale=3)
    elif s == 'Aberto':
        display.fill_rect(x+10, 170, 140, 60, cor2)
        display.text('Aberto', 193, 185, fg_color=cor1, bg_color=cor2, scale=3)

# Animação responsável pela responsividade dos oito botões inferiores
def tocar_botao(x, y, cor, comp, display, s):
    display.fill_rect(x, y, 80, 80, cor)
    display.fill_rect(x+5, y+5, 80-10, 80-10, comp)
    display.text(s, x + 80//2 - 15, y + 80//2 - 15, fg_color=cor, bg_color=comp, scale=3)

# Animação do led da BitDogLab responsável pelo halt do programa durante o movimento do braço robótico, aguardando por um segundo
def wait_movement(led_r, led_g, led_b):
    led(100, 100, 0, led_r, led_g, led_b)
    utime.sleep_ms(1000)
    led(0, 0, 50, led_r, led_g, led_b)

# EasterEgg
class RainbowColors():
    def __init__(self):
        self.color = 0x0000
    def next(self):
        if self.color == 0xFFFF : self.color = 0x0000
        else : self.color += 0xA
        return self.color

async def main():
    led_r, led_g, led_b, alto_falante, oled = init_bitdog()
    sender = BLE_Sender("Touch-Interface")
    # Flags
    end = False           # indica se o usuário pediu o encerramento da execução
    connecting = False    # indica se o texto "Conectando BLE..." já foi escrito no OLED
    initialized = False   # indica se as rotinas de inicialização já foram executadas
    # Cores
    BRANCO = 0x0000
    PRETO = 0xFFFF
    CINZA = 0x7BEF
    VERMELHO = 0x07FF
    VERDE = 0xF81F
    # EasterEgg
    rainbow = RainbowColors()
    while not end:
        if not sender.conectado:
            if not connecting:
                # Escrita no OLED para feedback ao usuário durante espera pela conexão à ESP32
                oled_write("Conectando", 25, 20, oled)
                oled_write("BLE...", 40, 30, oled)
                led(50, 0, 0, led_r, led_g, led_b)
                # Só precisa ser exibido uma vez, logo:
                connecting = True
            if initialized:
                # Caso a conexão caia, escreve no OLED para feedback ao usuário
                oled_write("Reconectando", 25, 20, oled)
                oled_write("BLE...", 40, 30, oled)
                led(50, 0, 0, led_r, led_g, led_b)
            # Solicitação de conexão
            await sender.conectar()
        else:
            if not initialized:
                # Rotinas de inicialização:
                led(0, 0, 50, led_r, led_g, led_b)                            # Led azul acende para indicar conexão bem sucedida
                play([(392, 1), (415, 1), (440, 1)], alto_falante)            # Música para indicar conexão bem sucedida
                oled_write("BLE conectado!", 10, 20, oled, fill=True)         # Escrita no OLED para indicar conexão bem sucedida
                oled_write("Inicializando", 12, 30, oled)
                display, touch, spi = init(BRANCO, PRETO)                     # Inicialização do SPI, touch e LCD
                await asyncio.sleep(2)                                        # Espera pela inicialização
                await sender.enviar_caractere('4', oled, 'U1', 40, False)     # Posição inicial: 4 ("U1")
                await asyncio.sleep(0.5)
                await sender.enviar_caractere('9', oled, 'Abrir', 40, False)  # Posição inicial: 9 (Garra aberta)
                # Flags para lógica de toque ("anti bouncing")
                U1, U2, U3, U4 = False, False, False, False
                D1, D2, D3, D4 = False, False, False, False
                # Flags específicas
                openit, closeit, opened, closed = False, False, True, False
                touched = False
                # Temporizações incrementais
                k, n, ee = 0, 0, 0
                # Feedback de fim da inicialização no OLED
                oled_write("Inicializado", 12, 20, oled, fill=True)
                oled_write("com sucesso", 14, 30, oled)
                initialized = True
            # Lógicas de código a serem executadas durante o toque
            if touch.is_touched():
                # Se o contador de encerramento tiver chegado em 200 (~2s)
                if k == 200:
                    # Rotina de encerramento
                    end = True
                    oled_write("Desconectando", 10, 20, oled, fill=True)            # Feedback visual no OLED
                    oled_write("e encerrando", 12, 30, oled)
                    play([(392, 1), (369, 1), (392, 1), (523, 2)], alto_falante)    # Música de encerramento
                    set_spi_speed(50_000_000, spi)
                    display.fill(PRETO)                                             # Apagar display LCD
                    await sender.desconectar()                                      # Encerrar BLE
                    led(0, 0, 0, led_r, led_g, led_b)                               # Apagar led da BitDogLab
                    oled.fill(0)                                                    # Apagar OLED
                    oled.show()
                # Se o toque tem o intuito de fechar
                if closeit:
                    k += 1
                # Se o botão acabou de ser tocado
                if not touched:
                    # Atualiza flag
                    touched = True
                    # Lê a posição do toque
                    y, x, z = touch.read()
                    p_x = int(x * 320)
                    p_y = int(y * 240)
                    # Acelera para animações
                    set_spi_speed(30_000_000, spi)
                    # Lógica de detecção do toque por pooling. Todos atualizam flags para animações e demais lógicas
                    if not D1 and 0 <= p_x < 80 and 0 <= p_y < 80: # D1
                        tocar_botao(0, 0, VERDE, PRETO, display, 'D1')
                        D1 = True
                    elif not D2 and 80 <= p_x < 160 and 0 <= p_y < 80: # D2
                        tocar_botao(80, 0, PRETO, VERDE, display, 'D2')
                        D2 = True
                    elif not D3 and 160 <= p_x < 240 and 0 <= p_y < 80: # D3
                        tocar_botao(160, 0, VERDE, PRETO, display, 'D3')
                        D3 = True
                    elif not D4 and 240 <= p_x < 320 and 0 <= p_y < 80: # D4
                        tocar_botao(240, 0, PRETO, VERDE, display, 'D4')
                        D4 = True
                    elif not U1 and 0 <= p_x < 80 and 80 <= p_y < 160: # U1
                        tocar_botao(0, 80, PRETO, VERDE, display, 'U1')
                        U1 = True
                    elif not U2 and 80 <= p_x < 160 and 80 <= p_y < 160: # U2
                        tocar_botao(80, 80, VERDE, PRETO, display, 'U2')
                        U2 = True
                    elif not U3 and 160 <= p_x < 240 and 80 <= p_y < 160: # U3
                        tocar_botao(160, 80, PRETO, VERDE, display, 'U3')
                        U3 = True
                    elif not U4 and 240 <= p_x < 320 and 80 <= p_y < 160: # U4
                        tocar_botao(240, 80, VERDE, PRETO, display, 'U4')
                        U4 = True
                    elif not closeit and 0 <= p_x < 160 and 160 <= p_y < 240: # Close
                        # Flag identifica intuito de fechar
                        closeit = True
                        if closed:
                            tocar_garra(0, VERMELHO, PRETO, display, 'Fechado')
                        else:
                            tocar_garra(0, VERDE, PRETO, display, 'Fechar')
                    elif not openit and 160 <= p_x < 320 and 160 <= p_y < 240: # Open
                        # Flag identifica intuito de abrir
                        openit = True
                        if opened:
                            tocar_garra(160, VERMELHO, PRETO, display, 'Aberto')
                        else:
                            tocar_garra(160, VERDE, PRETO, display, 'Abrir')
            else:
                # Atualiza flag
                touched = False
                # Pooling para animações que disparam ao soltar o botão. Todos os oito botões inferiores são iguais
                if D1:
                    # Acelera SPI
                    set_spi_speed(50_000_000, spi)
                    # Atualzia flag
                    D1 = False
                    # EasterEgg counter
                    ee -= 1
                    # Animações e envio do caractere
                    tocar_botao(0, 0, BRANCO, PRETO, display, 'D1')
                    await asyncio.sleep(0.5)
                    await sender.enviar_caractere('0', oled, 'D1', 50)
                    wait_movement(led_r, led_g, led_b)
                elif D2:
                    set_spi_speed(50_000_000, spi)
                    D2 = False
                    tocar_botao(80, 0, PRETO, BRANCO, display, 'D2')
                    await asyncio.sleep(0.5)
                    await sender.enviar_caractere('1', oled, 'D2', 50)
                    wait_movement(led_r, led_g, led_b)
                elif D3:
                    set_spi_speed(50_000_000, spi)
                    D3 = False
                    tocar_botao(160, 0, BRANCO, PRETO, display, 'D3')
                    await asyncio.sleep(0.5)
                    await sender.enviar_caractere('2', oled, 'D3', 50)
                    wait_movement(led_r, led_g, led_b)
                elif D4:
                    set_spi_speed(50_000_000, spi)
                    D4 = False
                    tocar_botao(240, 0, PRETO, BRANCO, display, 'D4')
                    await asyncio.sleep(0.5)
                    await sender.enviar_caractere('3', oled, 'D4', 50)
                    wait_movement(led_r, led_g, led_b)
                elif U1:
                    set_spi_speed(50_000_000, spi)
                    U1 = False
                    # EasterEgg counter
                    ee += 1
                    tocar_botao(0, 80, PRETO, BRANCO, display, 'U1')
                    await asyncio.sleep(0.5)
                    await sender.enviar_caractere('4', oled, 'U1', 50)
                    wait_movement(led_r, led_g, led_b)
                elif U2:
                    set_spi_speed(50_000_000, spi)
                    U2 = False
                    tocar_botao(80, 80, BRANCO, PRETO, display, 'U2')
                    await asyncio.sleep(0.5)
                    await sender.enviar_caractere('5', oled, 'U2', 50)
                    wait_movement(led_r, led_g, led_b)
                elif U3:
                    set_spi_speed(50_000_000, spi)
                    U3 = False
                    tocar_botao(160, 80, PRETO, BRANCO, display, 'U3')
                    await asyncio.sleep(0.5)
                    await sender.enviar_caractere('6', oled, 'U3', 50)
                    wait_movement(led_r, led_g, led_b)
                elif U4:
                    set_spi_speed(50_000_000, spi)
                    U4 = False
                    tocar_botao(240, 80, BRANCO, PRETO, display, 'U4')
                    await asyncio.sleep(0.5)
                    await sender.enviar_caractere('7', oled, 'U4', 50)
                    wait_movement(led_r, led_g, led_b)
                elif closeit:
                    # Acelera SPI
                    set_spi_speed(50_000_000, spi)
                    # Atualiza flag
                    closeit = False
                    # Se estava aberto, o intuito de fechar realmente fecha
                    if opened:
                        # Animação
                        fechar(BRANCO, PRETO, display)
                        # Atualização de flags de estado
                        closed = True
                        opened = False
                        await asyncio.sleep(0.5)
                        # Envio de caractere
                        await sender.enviar_caractere('8', oled, 'Fechar', 40)
                        wait_movement(led_r, led_g, led_b)
                    # Se já estava fechado, intuito de fechar não manda caractere
                    else:
                        # Animação e feedback visual no OLED
                        tocar_garra(0, BRANCO, PRETO, display, 'Fechado')
                        oled_write("Garra foi", 30, 20, oled, fill=True)
                        oled_write("fechada", 38, 30, oled)
                # Lógica análoga ao closeit
                elif openit:
                    set_spi_speed(50_000_000, spi)
                    openit = False
                    if closed:
                        abrir(BRANCO, PRETO, display)
                        opened = True
                        closed = False
                        await asyncio.sleep(0.5)
                        await sender.enviar_caractere('9', oled, 'Abrir', 40)
                        wait_movement(led_r, led_g, led_b)
                    else:
                        tocar_garra(160, BRANCO, PRETO, display, 'Aberto')
                        oled_write("Garra foi", 30, 20, oled, fill=True)
                        oled_write("aberta", 40, 30, oled)
            # EasterEgg
            if ee >= 3:
                ee = 3
                if n%100 == 0:
                    print("Rainbow mode!")
                    BRANCO = rainbow.next()
                    set_spi_speed(50_000_000, spi)
                    montar_botoes(BRANCO, PRETO, display, fill=False)
                    if opened : abrir(BRANCO, PRETO, display)
                    if closed : fechar(BRANCO, PRETO, display)
                    set_spi_speed(1_000_000, spi)
                n += 1
            elif ee < 0 : ee = 0
            elif BRANCO != 0x0000:
                BRANCO = 0x0000
                ee = 0
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

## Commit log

2025-06-28 Adding arm control code
2025-06-28 Arm STLs Files for 3D Printing
    [Arm.stl, Assembled 3D Structure.stl, Ball Bearing Support.stl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]
2025-06-30 Update README.md
    Inserted image and gif demos
